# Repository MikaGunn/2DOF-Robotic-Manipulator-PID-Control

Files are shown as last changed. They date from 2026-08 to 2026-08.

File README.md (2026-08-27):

# 2-DOF Robotic Manipulator with PID Control

A complete mechatronics project covering the design, simulation, fabrication, electronics integration and closed loop control of a **2 degree of freedom (2-DOF) planar robotic manipulator**.

The system combines mechanical CAD design, 3D printed components, Arduino based motor control, encoder feedback, inverse kinematics and PID position control developed in MATLAB/Simulink.

<p align="center">
  2-DOF robotic manipulator
</p>

## Project Overview

The manipulator was developed as part of a university robotics and mechatronics project. Its two rotational joints allow the end effector to move within a 2D workspace. A belt and pulley transmission was used for the second link to improve stability and reduce the need to mount an additional motor directly on the moving arm.

The project includes:

- Mechanical concept development and CAD modelling
- Forward and inverse kinematics
- Denavit Hartenberg modelling
- 3D-printed custom components
- Arduino Mega 2560 control
- EMG30 DC motors with encoders
- L298N H-bridge motor driver
- Closed loop PID position control
- MATLAB/Simulink control system development
- Encoder feedback and PWM motor actuation
- Experimental PID tuning and response analysis

## System Architecture

The control system receives a desired end effector position and converts it into target joint angles using inverse kinematics. Each joint then uses encoder feedback and PID control to reduce the difference between the desired and measured angular position.

```text
Target End-Effector Position (x, y)
              |
              v
      Inverse Kinematics
              |
        theta1, theta2
          /       \
         v         v
     PID Joint 1  PID Joint 2
         |           |
         v           v
     Motor Driver  Motor Driver
         |           |
         v           v
      DC Motor 1   DC Motor 2
         ^           ^
         |           |
      Encoder 1    Encoder 2
         \___________/
          Feedback Loop
```

<p align="center">
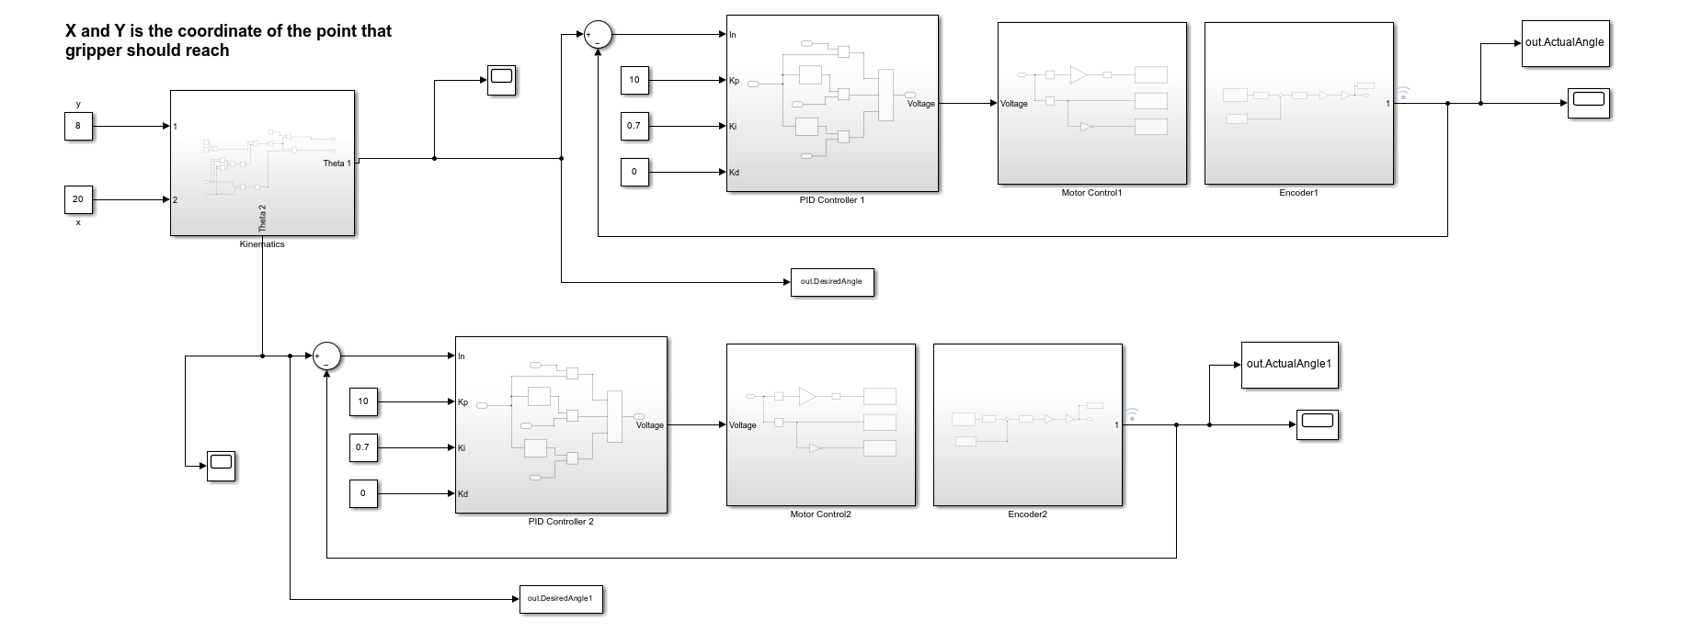
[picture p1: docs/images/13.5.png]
Simulink control architecture
  
</p>

## Mechanical Design

CAD modelling was carried out using **Onshape** and **SolidWorks**. The assembly includes two rotational joints, two links, a gripper, belt and pulley transmission, motors, bearings and custom printed interfaces.

Two custom parts designed for the system include:

- **Gripper** — includes inner gripping channels and a square mounting interface for the arm.
- **Motor joint** — designed to securely connect the EMG30 motor to the first arm and transfer rotational motion.

The complete CAD assembly is included as a STEP file in the `CAD/` directory.

<p align="center">
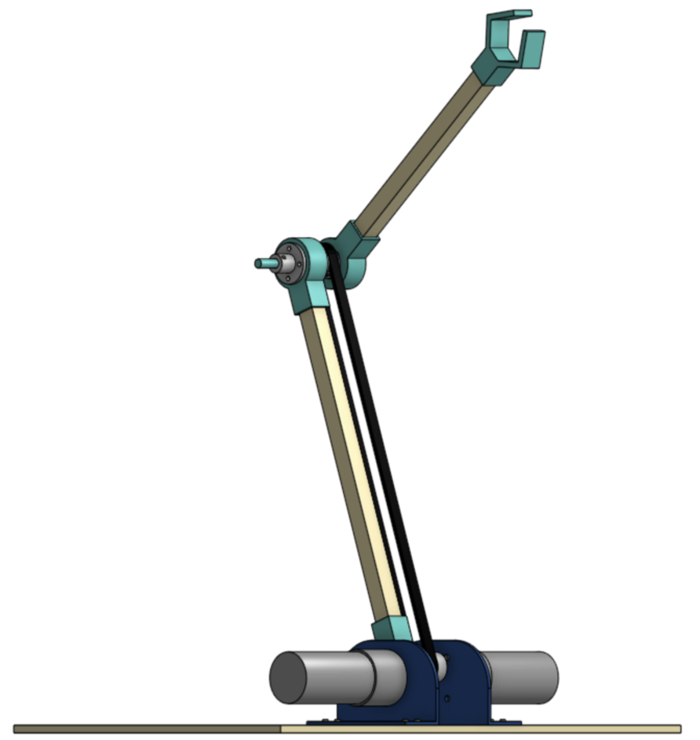
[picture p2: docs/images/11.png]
CAD assembly
  
</p>

## Electronics

### Main Components

| Component | Purpose |
|---|---|
| Arduino Mega 2560 | Main controller and encoder interface |
| 2 × EMG30 DC motors with encoders | Joint actuation and position feedback |
| L298N motor driver | Bidirectional motor control |
| 12 V external power supply | Motor power |
| GT2 belt and pulleys | Motion transmission to the second link |

The Arduino reads encoder signals, computes motor position error and drives the motors through PWM and direction signals.

## PID Control

Each joint uses a feedback PID controller. The control objective is to track the target joint position while reducing overshoot, rise time and steady state error.

The tuned controller values used in the project were:

| Gain | Value |
|---|---:|
| Kp | 1.0 |
| Ki | 0.7 |
| Kd | 0.0 |

The Arduino implementation updates the PID calculation every **50 ms**, includes encoder interrupt handling, output limiting and a minimum PWM compensation to overcome motor deadband/static friction.

<p align="center">
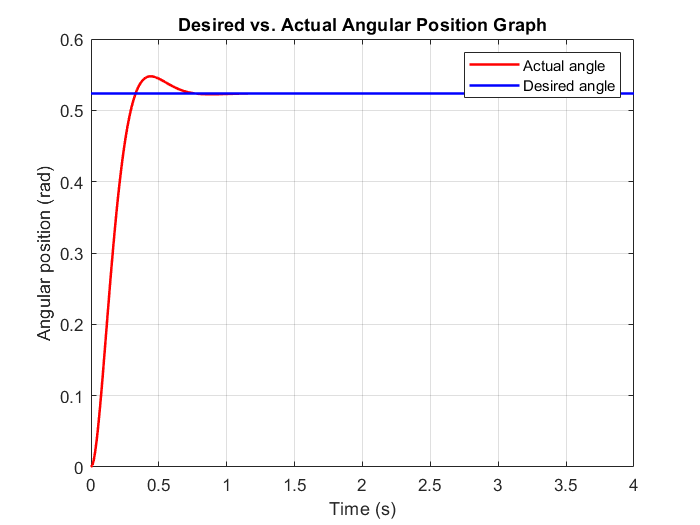
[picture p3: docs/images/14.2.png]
PID response result
  
</p>

## Kinematics

For a planar 2-link manipulator, the end effector coordinates are determined from the link lengths and joint angles.

Forward kinematics:

```text
x = L1 cos(theta1) + L2 cos(theta1 + theta2)
y = L1 sin(theta1) + L2 sin(theta1 + theta2)
```

Inverse kinematics is used to calculate the two required joint angles for a desired `(x, y)` end effector target.

## Repository Structure

```text
2DOF-Robotic-Manipulator-PID-Control/
├── CAD/
│   └── Robot_CAD.step
├── control/
│   ├── Arduino_PID_controller.ino
│   └── Simulink_PID_controller.slx
├── docs/
│   └── images
│   └── 2DOF Robotic Manipulator Report
├── .gitignore
└── README.md
```

## Files

### `CAD/Robot_CAD.step`
Full 3D CAD assembly of the robotic manipulator in STEP format.

### `control/Simulink_PID_controller.slx`
MATLAB/Simulink model containing the kinematics, PID, motor control and encoder feedback subsystems.

### `control/Arduino_PID_controller.ino`
Arduino implementation of the dual motor PID controller. It includes:

- Encoder interrupts
- Independent PID loops for both motors
- PWM motor output
- Direction control
- Error threshold handling
- Minimum PWM compensation
- Automatic target switching for repeated motion tests
- Serial monitoring of position and target values

## Hardware Used

- Arduino Mega 2560
- 2 × EMG30 DC motors with encoders
- L298N dual H-bridge motor driver
- GT2 belt and pulley system
- Bearings and shaft components
- 3D printed gripper and mechanical joints
- Wooden arm links and base
- 12 V motor power supply

## Software Used

- MATLAB
- Simulink
- Arduino IDE
- SolidWorks
- Onshape

## Key Engineering Challenges

The project highlighted several practical robotics challenges:

- Mechanical alignment influenced encoder accuracy.
- Belt tension affected vibration and motion quality.
- Gravity had a larger effect on the first joint because it supported the complete arm assembly.
- PID tuning required balancing response speed, overshoot and steady state error.
- Some Simulink to hardware compilation issues led to development of a standalone Arduino PID implementation as an alternative controller.

## Future Improvements

Possible extensions include:

- Dual sided axle support to improve rigidity
- Aluminium or carbon fibre links to reduce flex and vibration
- Servo actuated gripper
- Improved cable management
- Trajectory planning instead of point to point motion
- Automatic PID tuning
- Workspace and path visualisation
- ROS 2 integration
- Joint limit and safety protection

## Skills Demonstrated

`Robotics` · `Mechatronics` · `Control Systems` · `PID Control` · `Arduino` · `MATLAB` · `Simulink` · `CAD` · `SolidWorks` · `Onshape` · `3D Printing` · `Forward Kinematics` · `Inverse Kinematics` · `Encoder Feedback` · `PWM Motor Control`

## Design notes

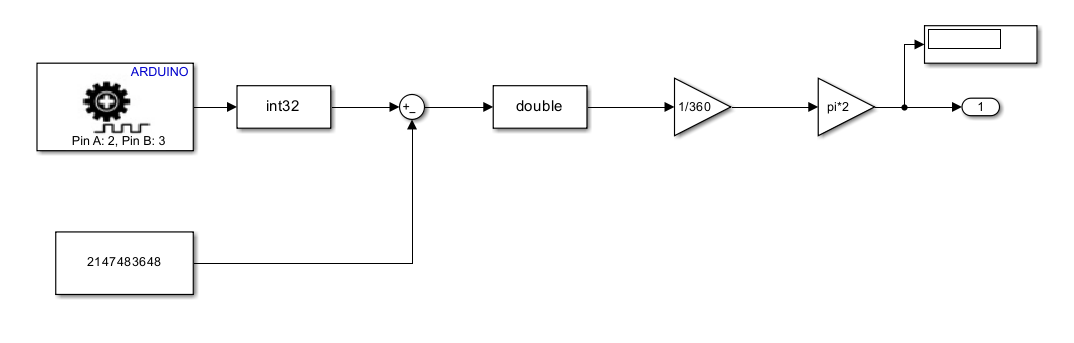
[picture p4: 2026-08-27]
docs/images/13.1.png

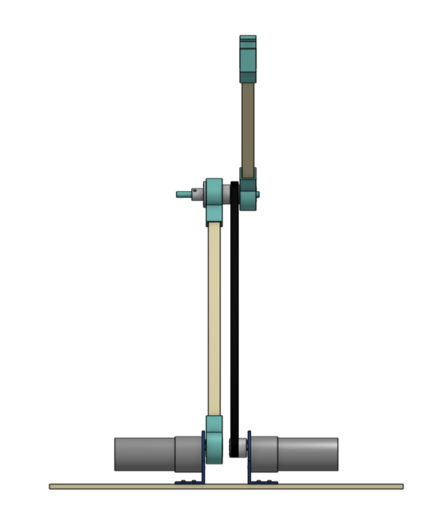
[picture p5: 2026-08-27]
docs/images/9.0.png

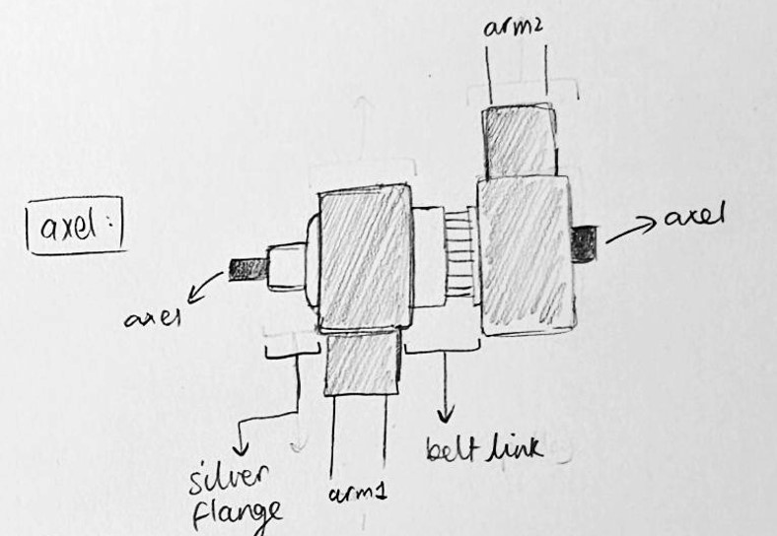
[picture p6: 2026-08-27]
docs/images/8.1.jpg

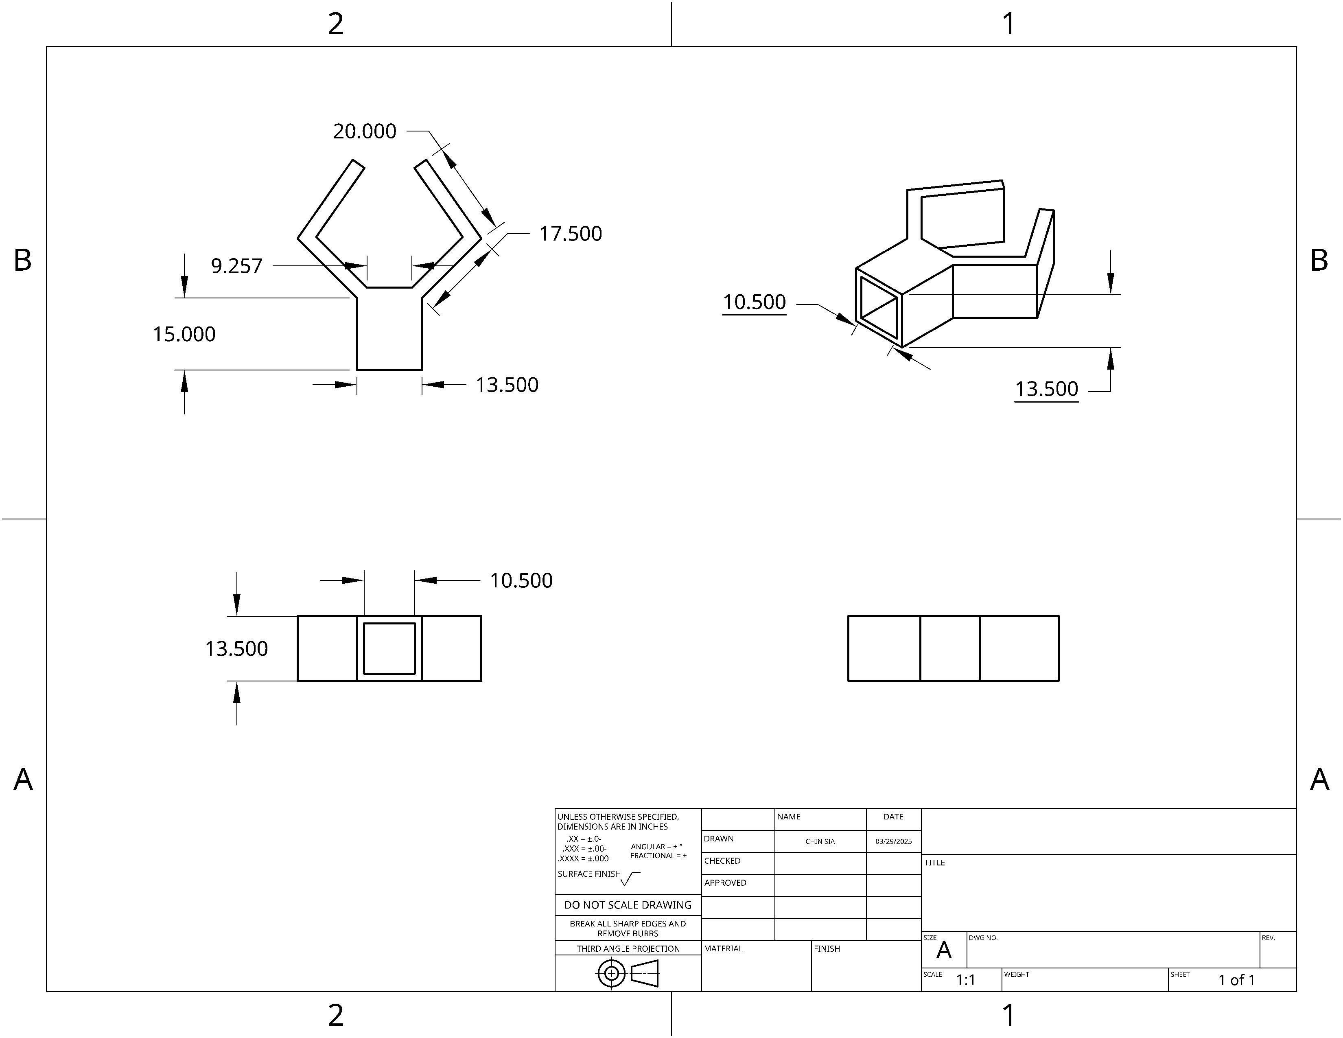
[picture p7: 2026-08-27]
docs/images/7.1.jpeg

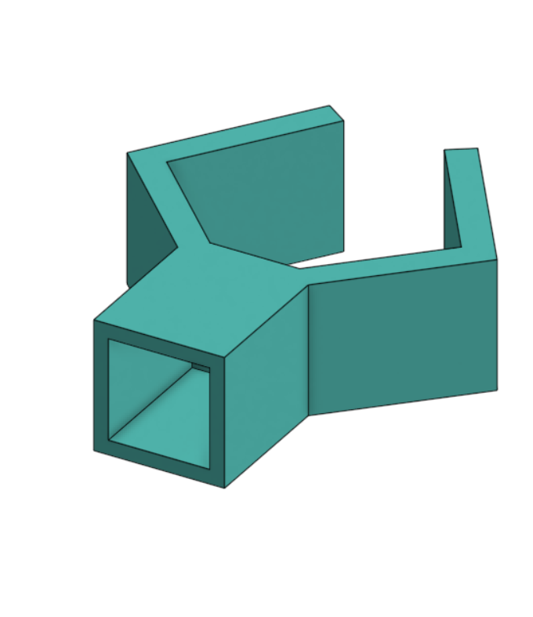
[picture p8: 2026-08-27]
docs/images/7.0.png

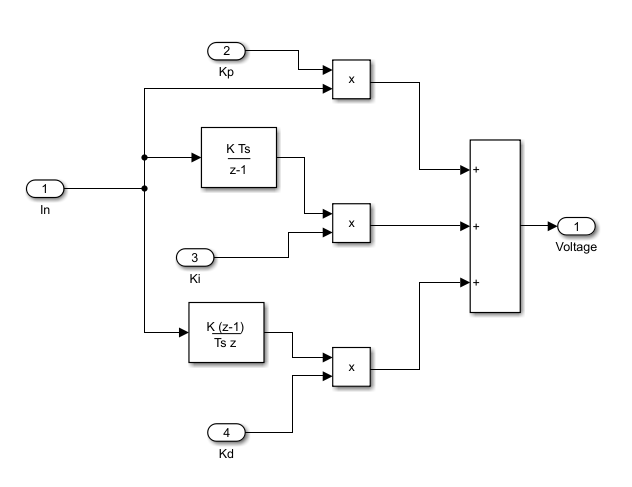
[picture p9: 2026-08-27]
docs/images/13.0.png

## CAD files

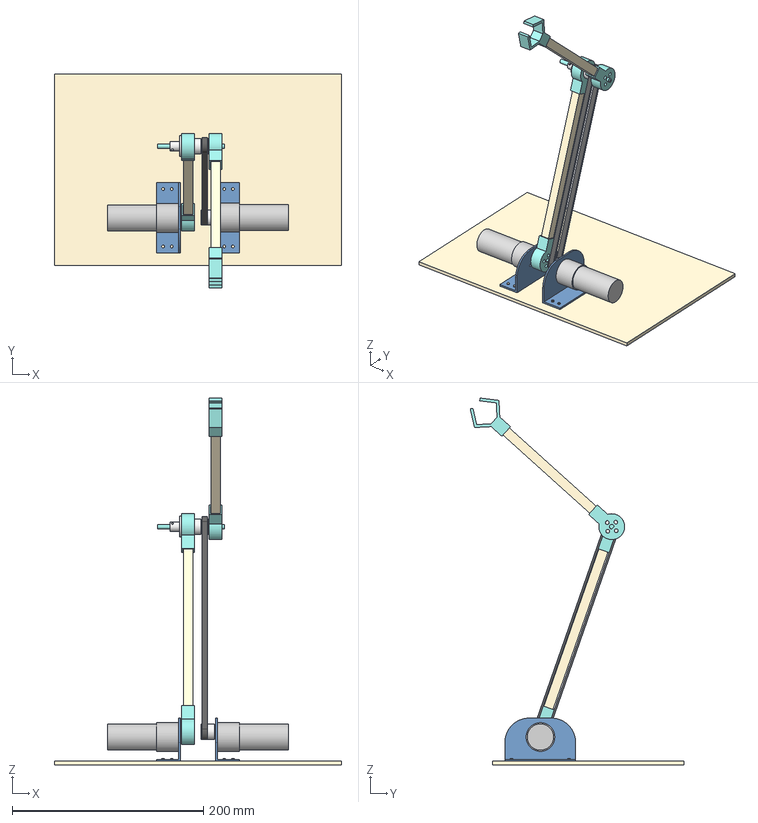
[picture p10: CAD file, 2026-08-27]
CAD/Robot_CAD.step
300.0 x 223.2 x 383.4 mm
Spur gear (20 teeth) x 2

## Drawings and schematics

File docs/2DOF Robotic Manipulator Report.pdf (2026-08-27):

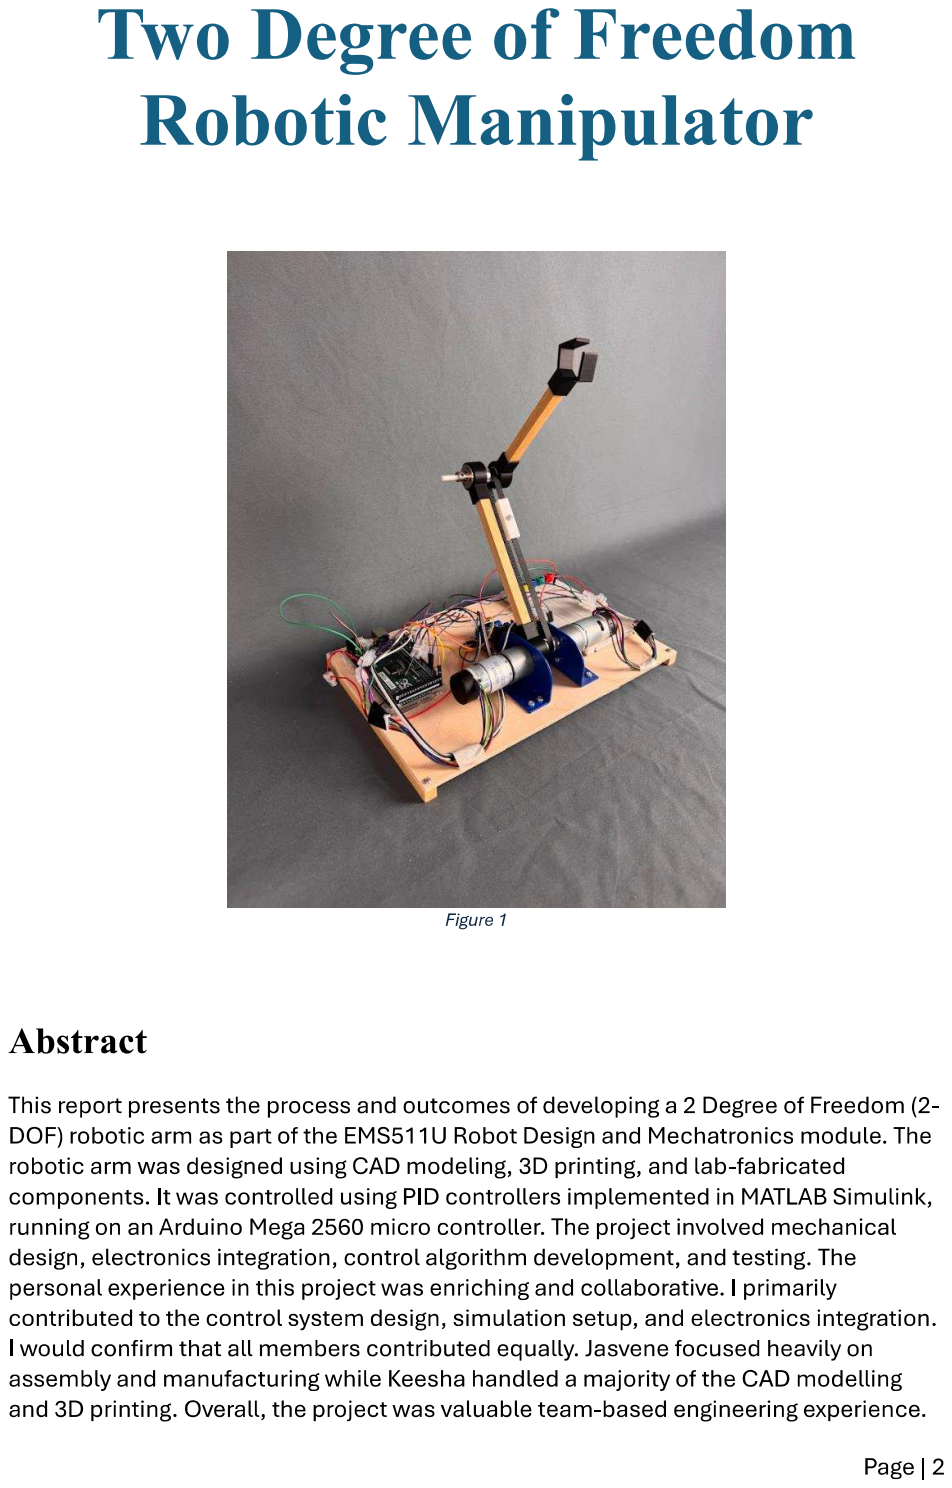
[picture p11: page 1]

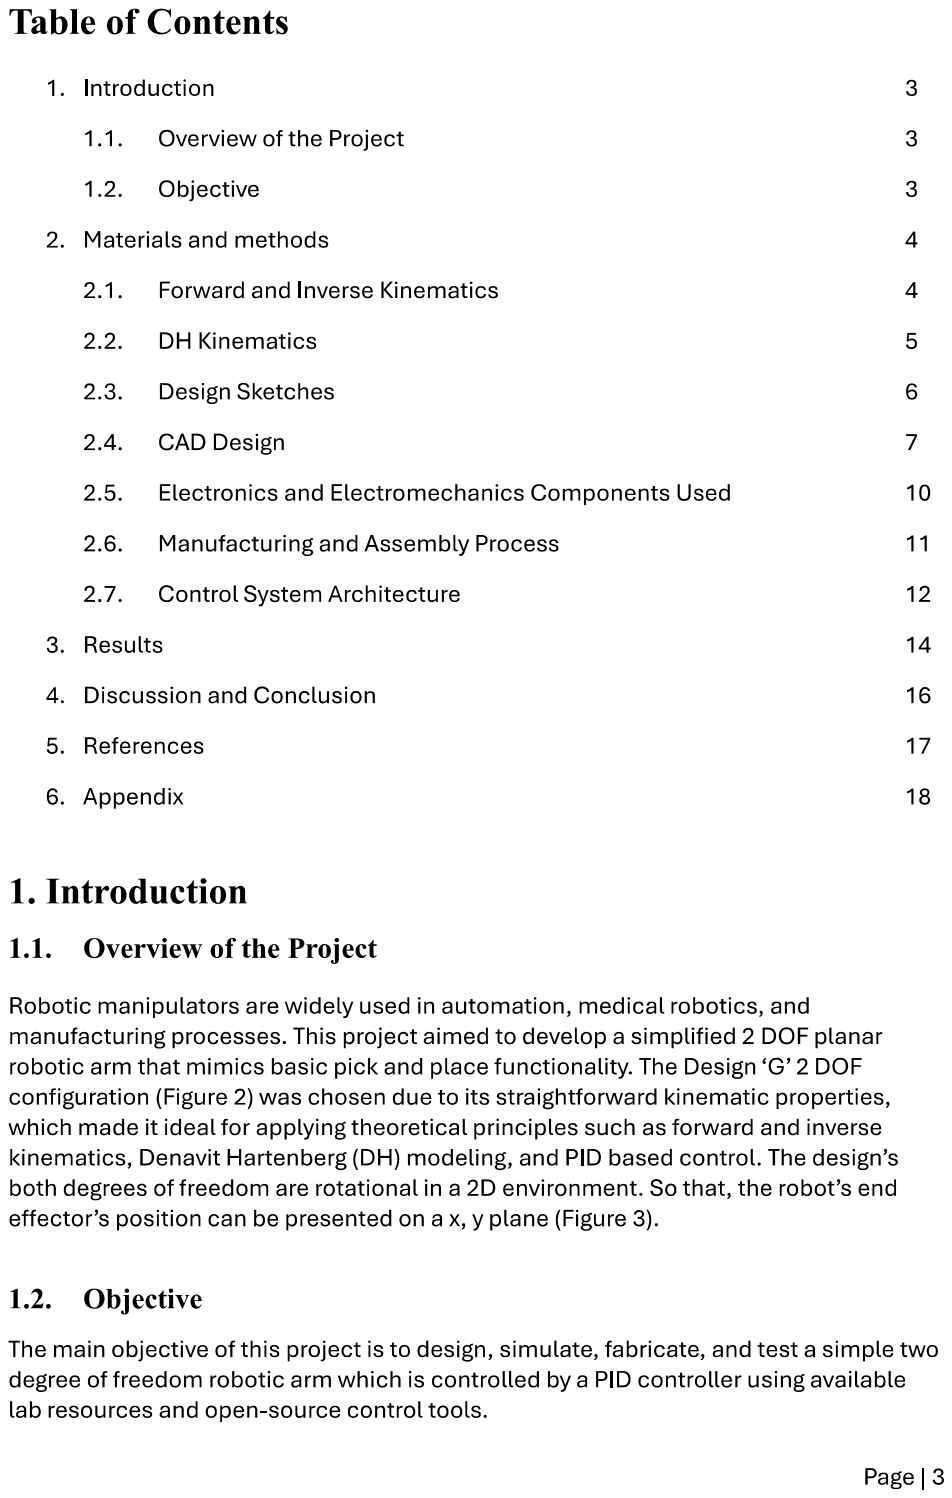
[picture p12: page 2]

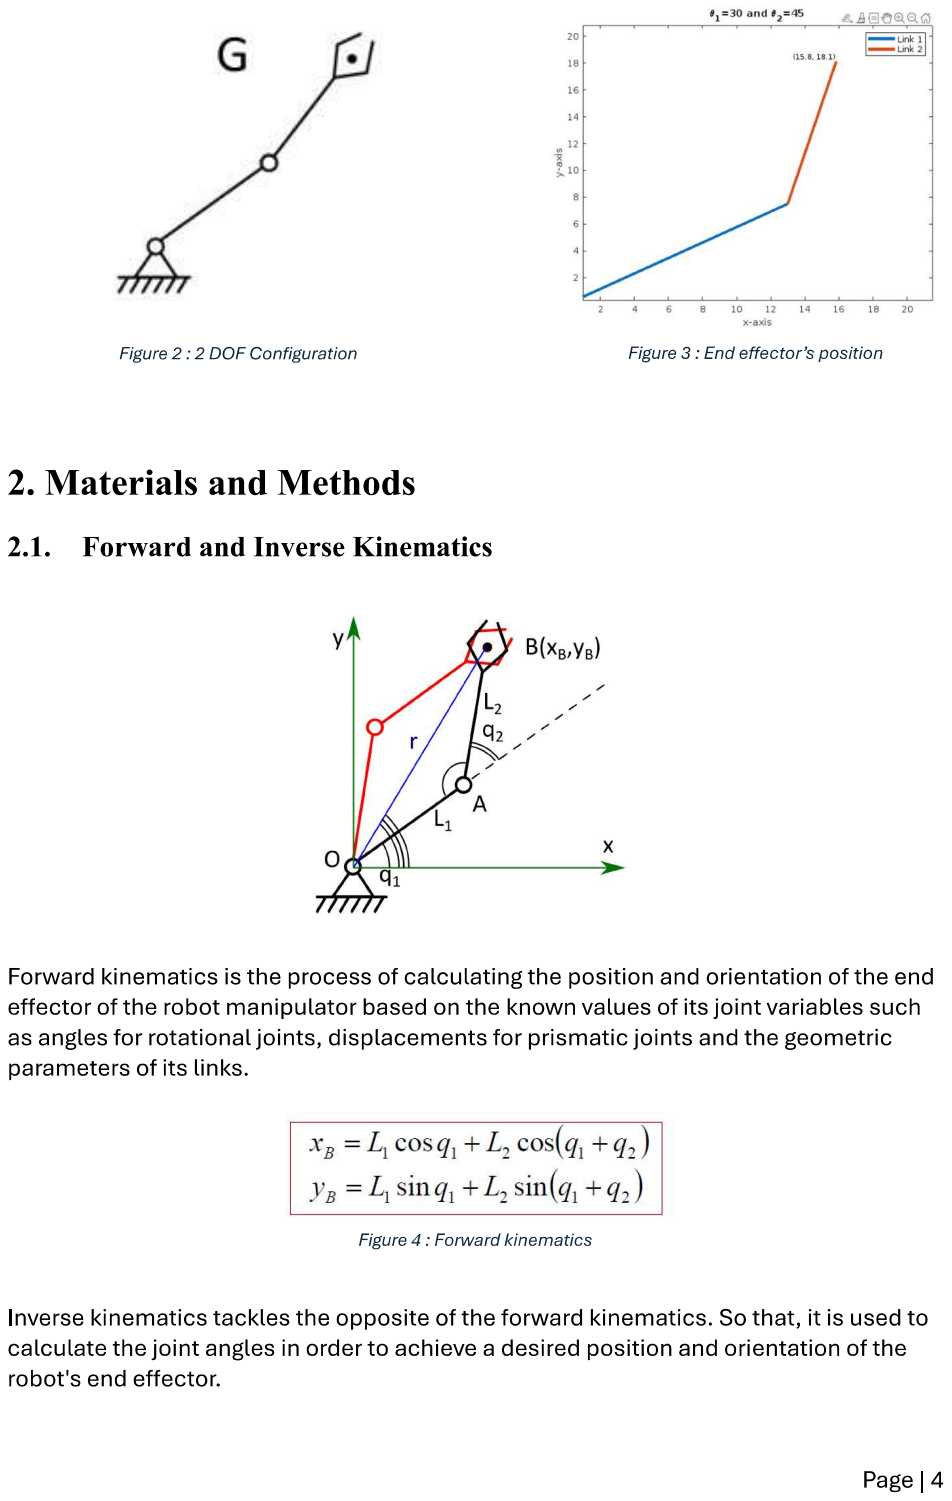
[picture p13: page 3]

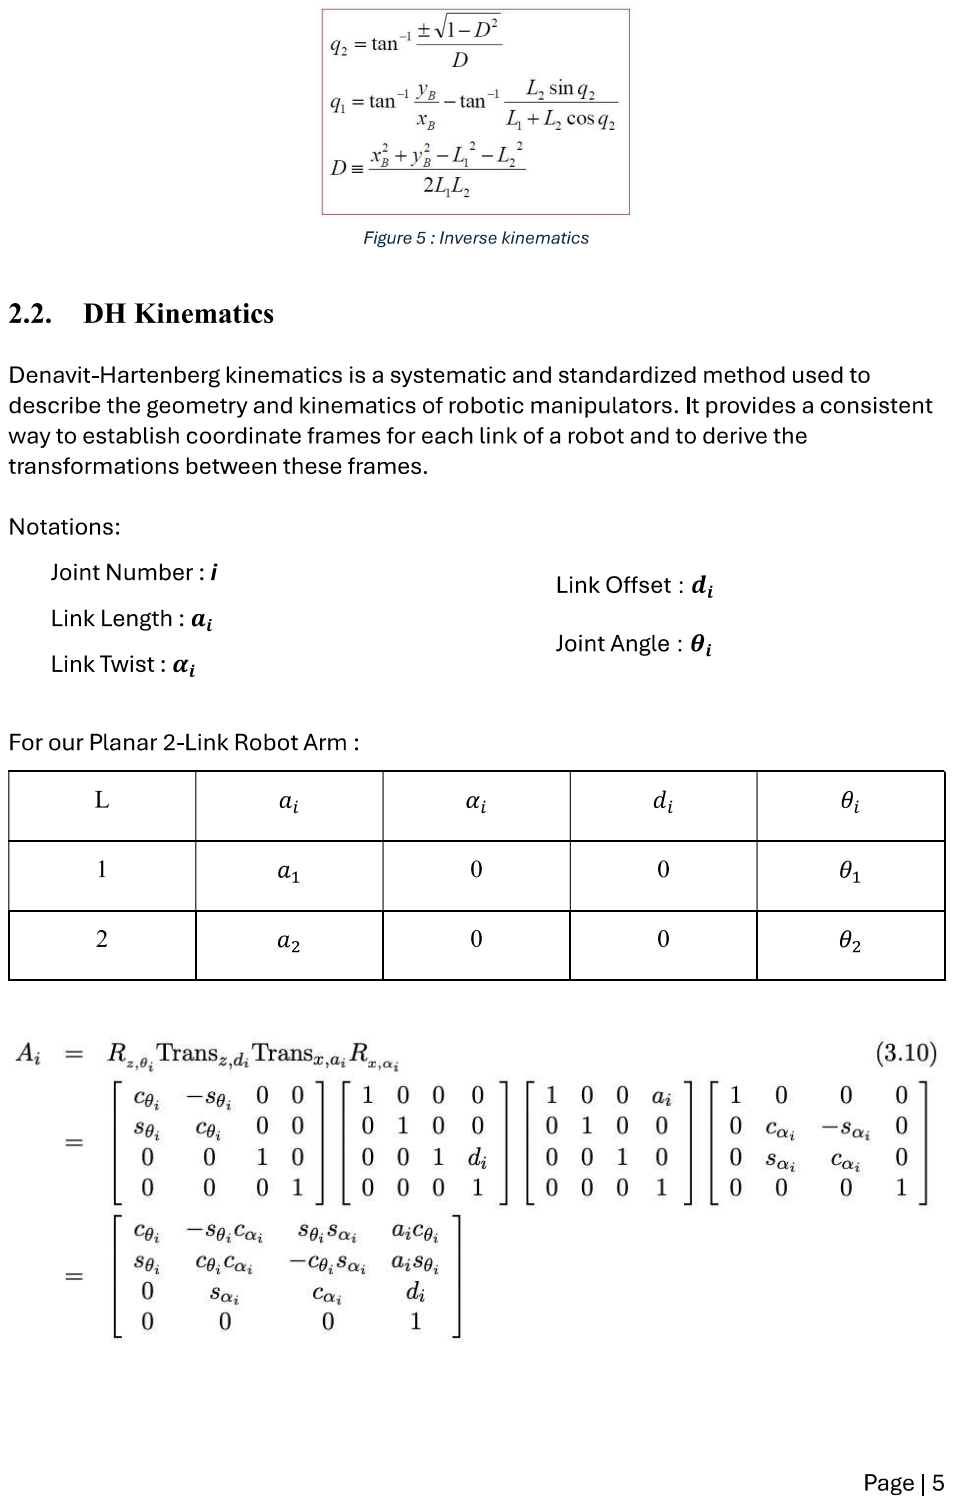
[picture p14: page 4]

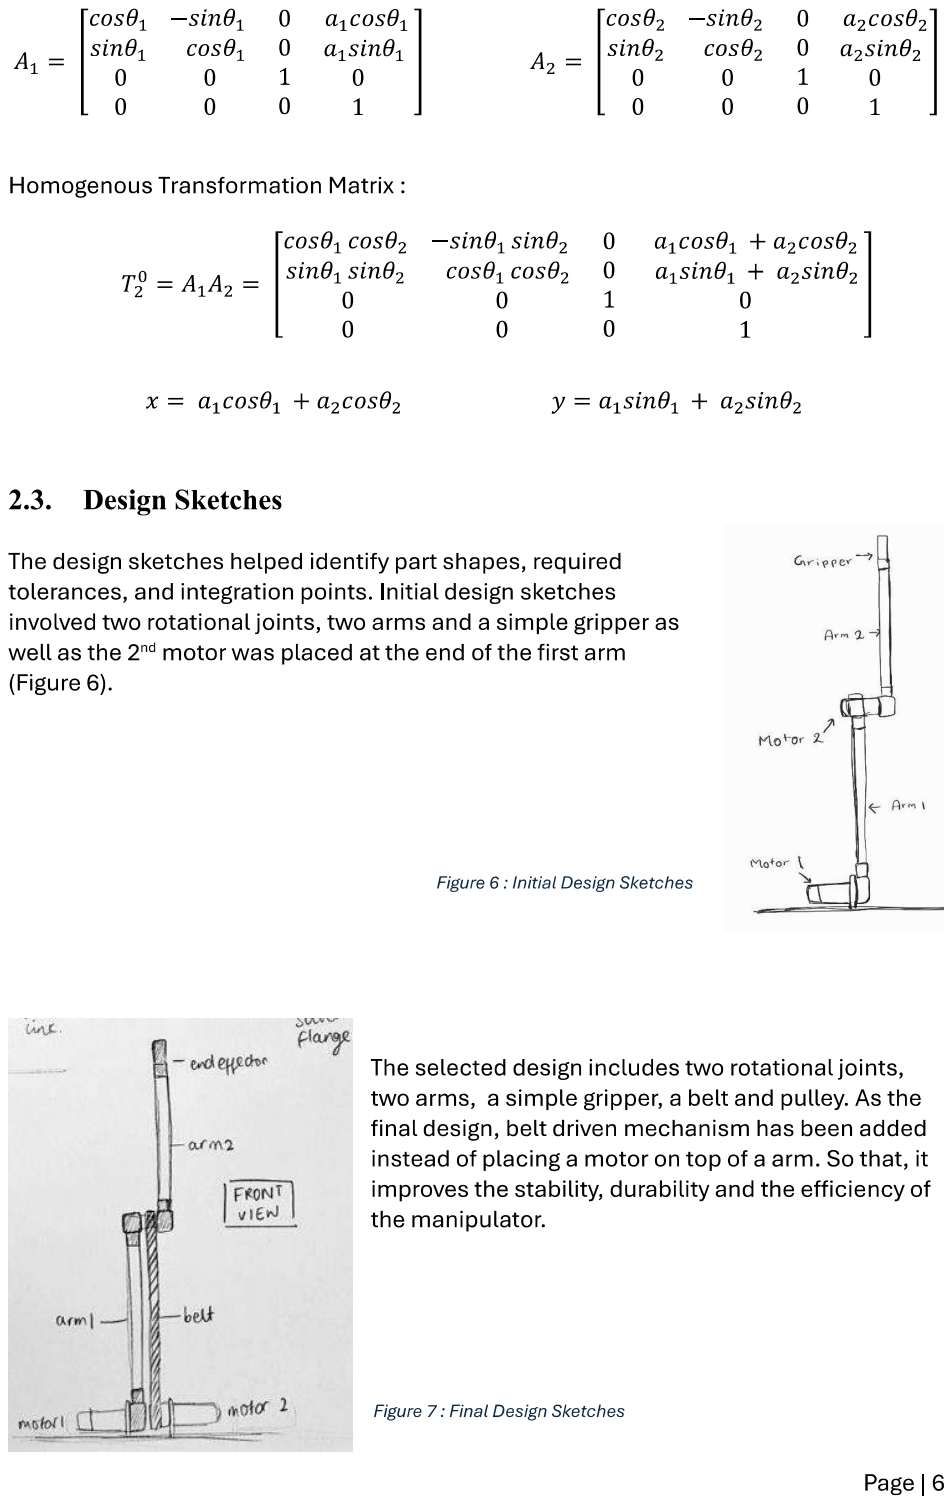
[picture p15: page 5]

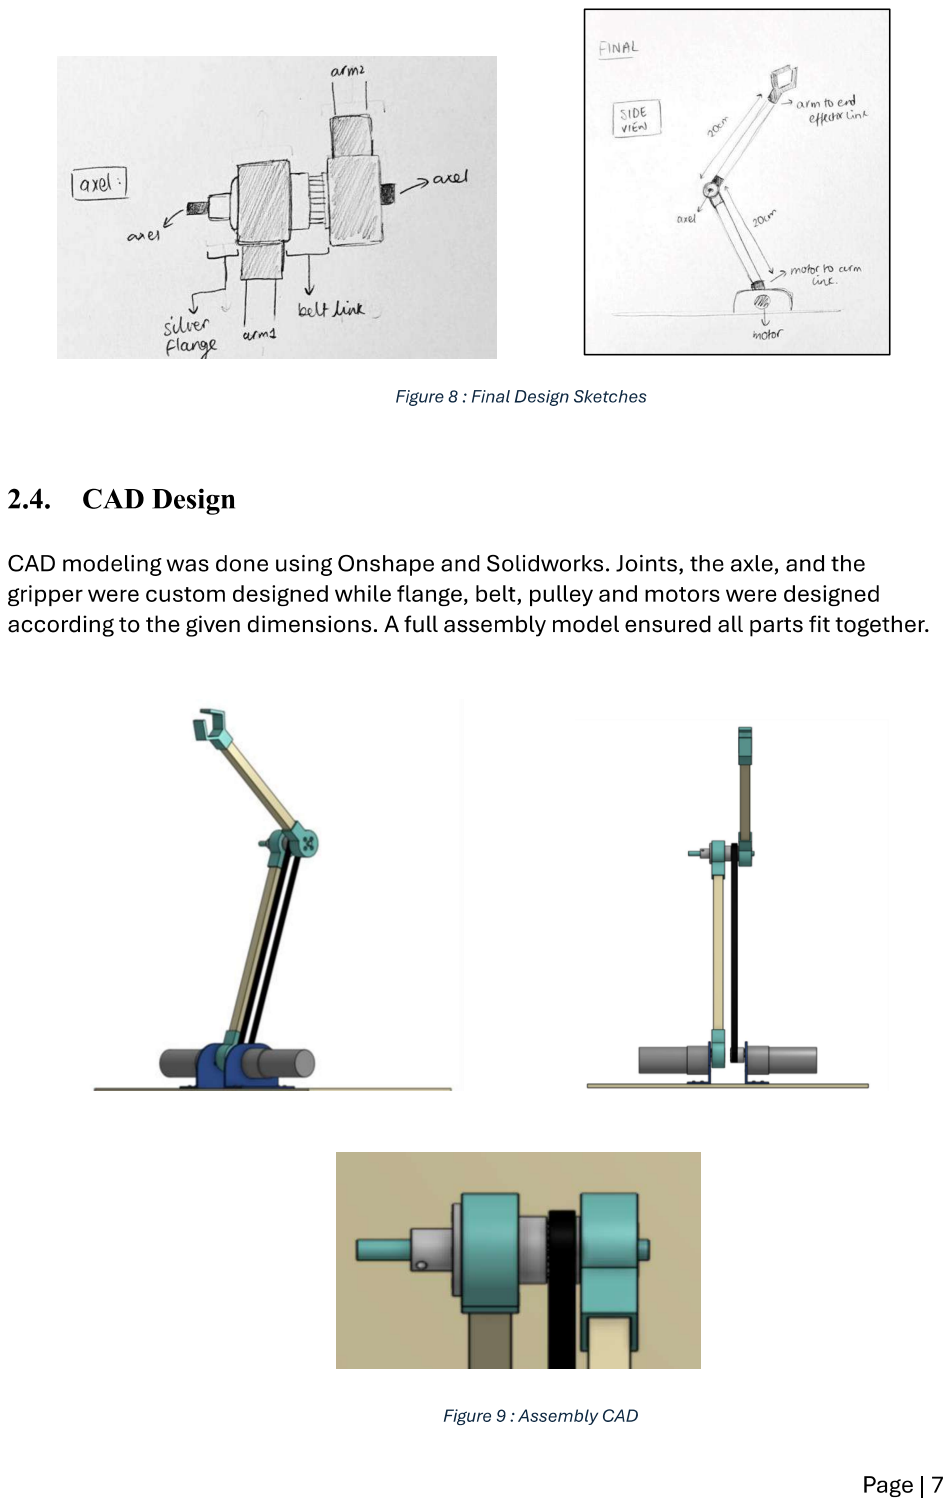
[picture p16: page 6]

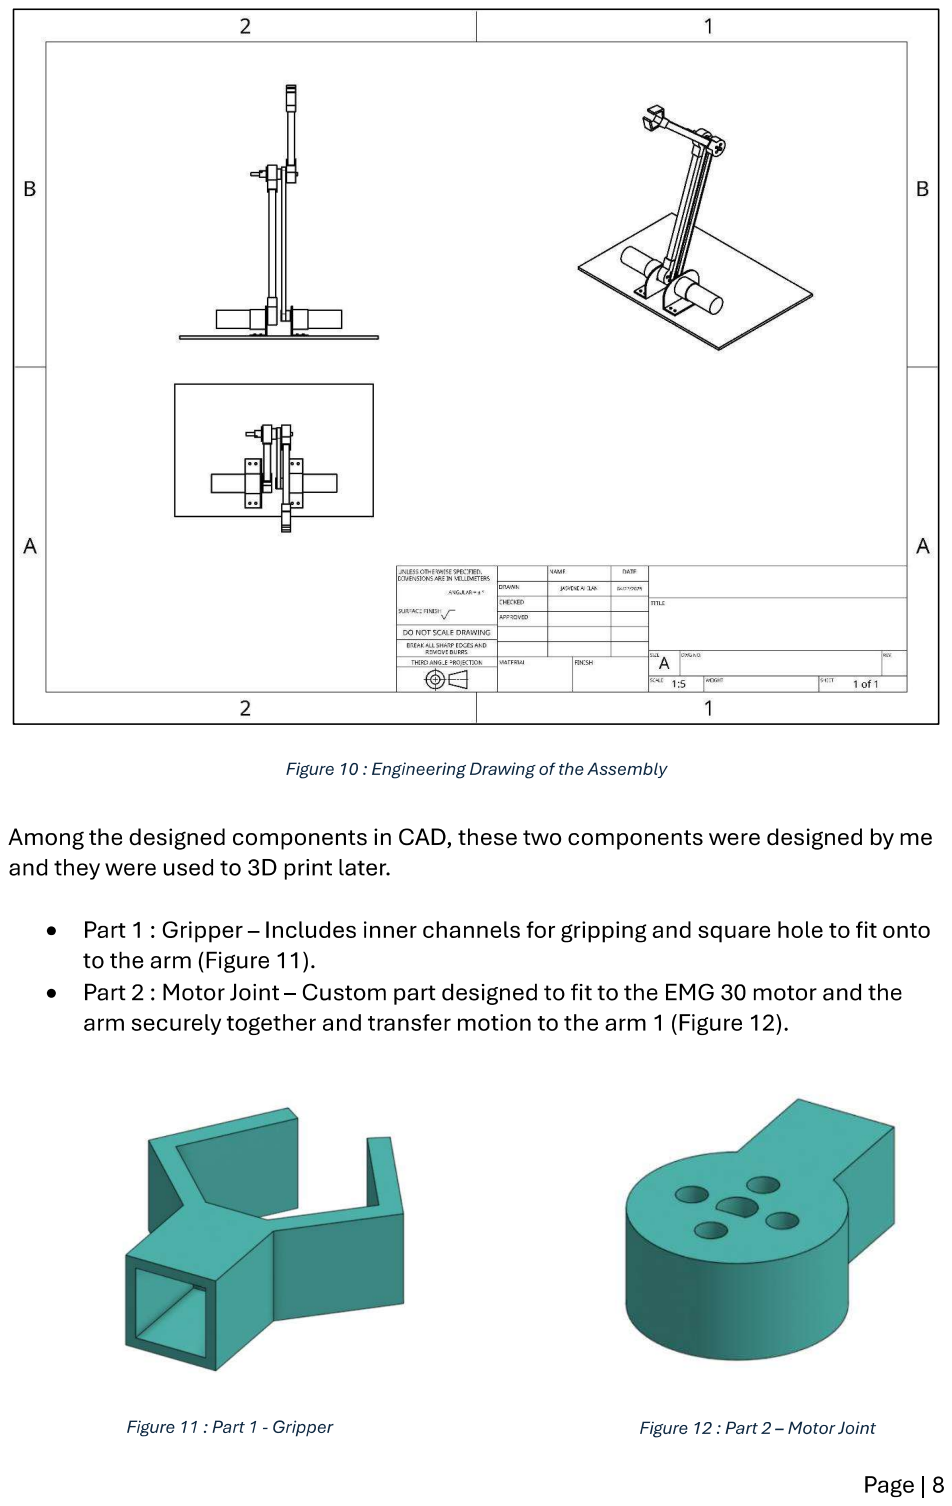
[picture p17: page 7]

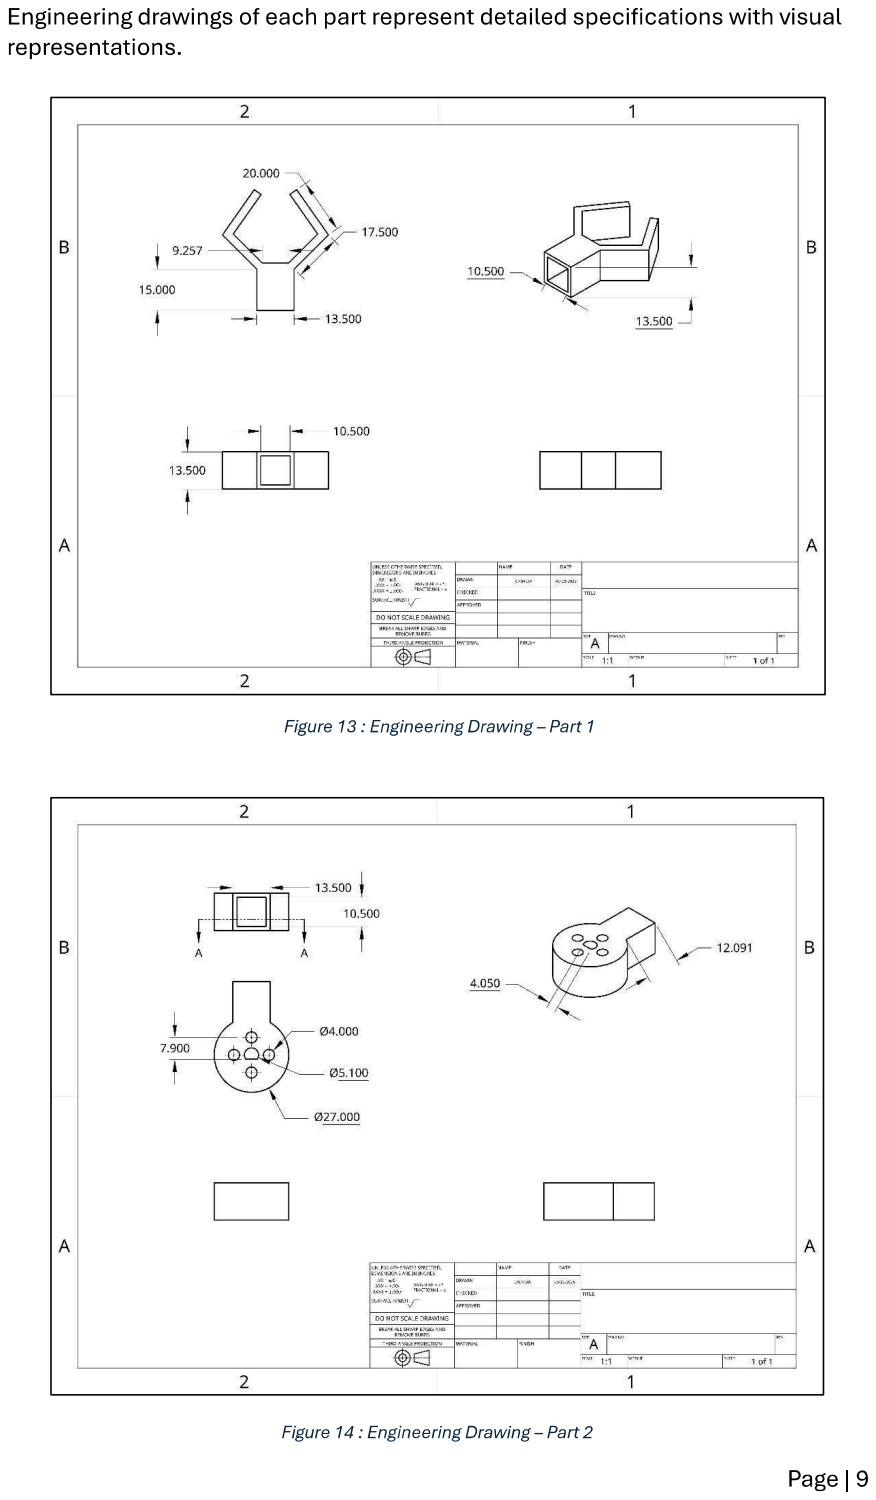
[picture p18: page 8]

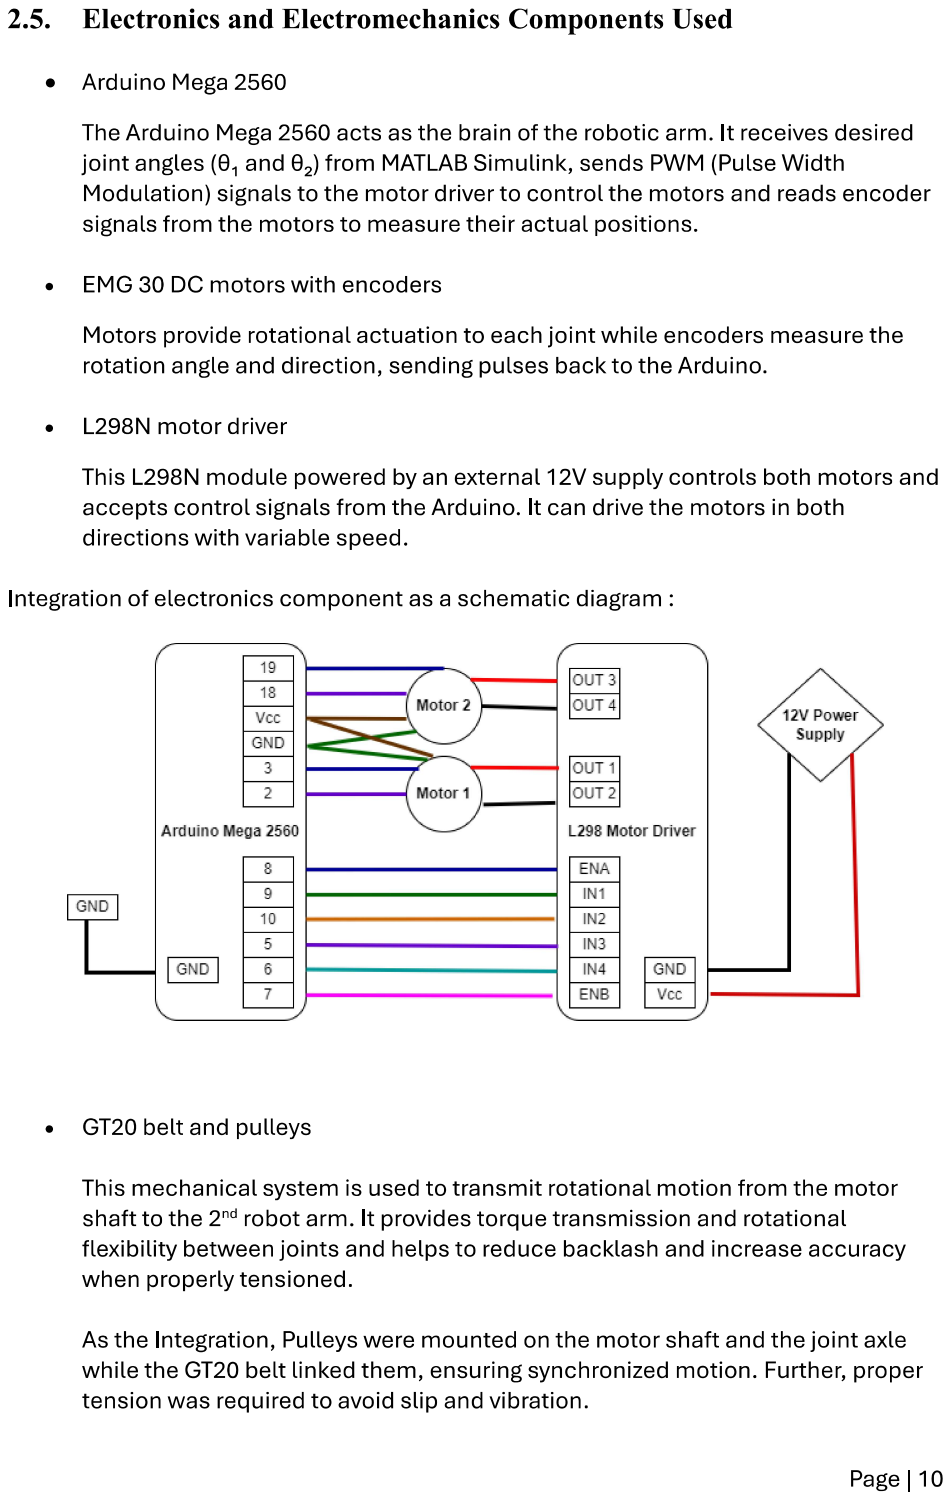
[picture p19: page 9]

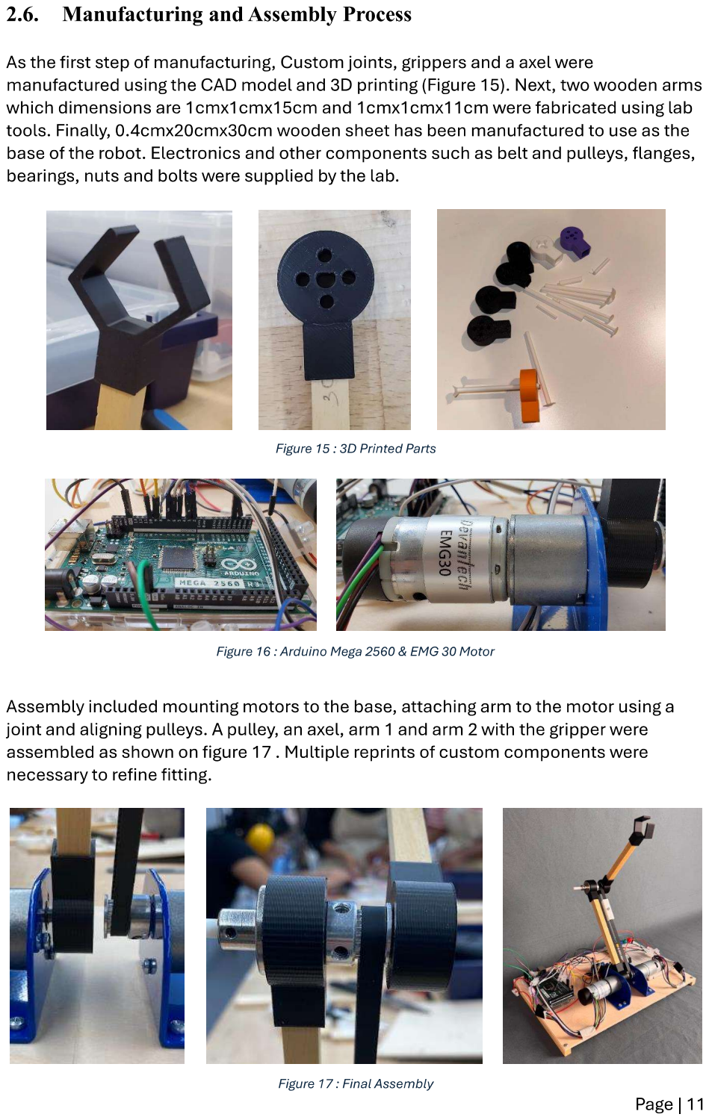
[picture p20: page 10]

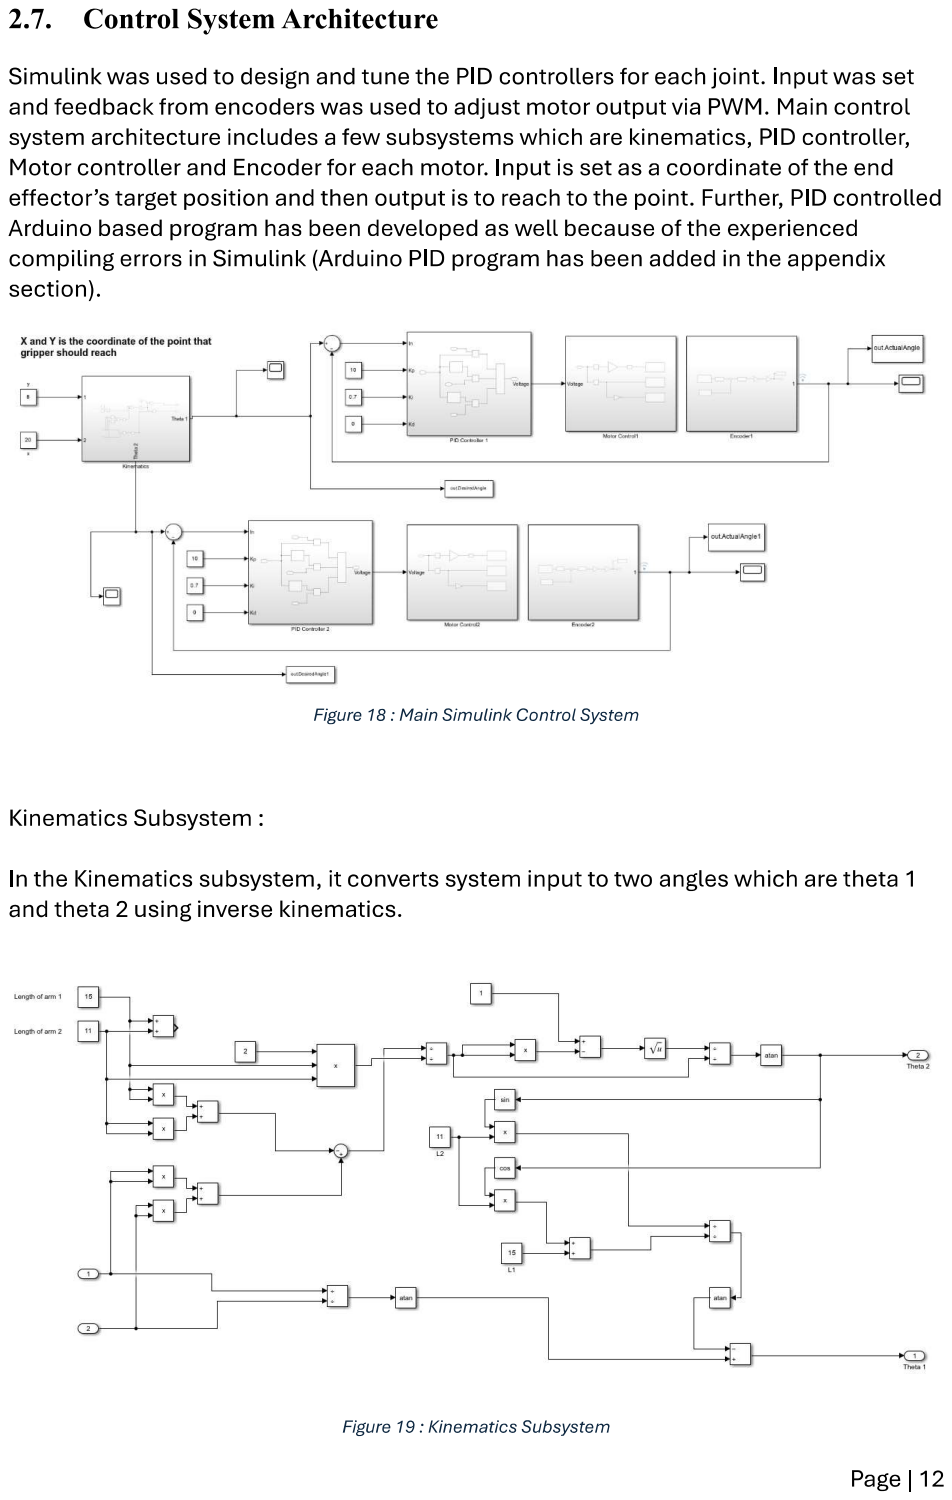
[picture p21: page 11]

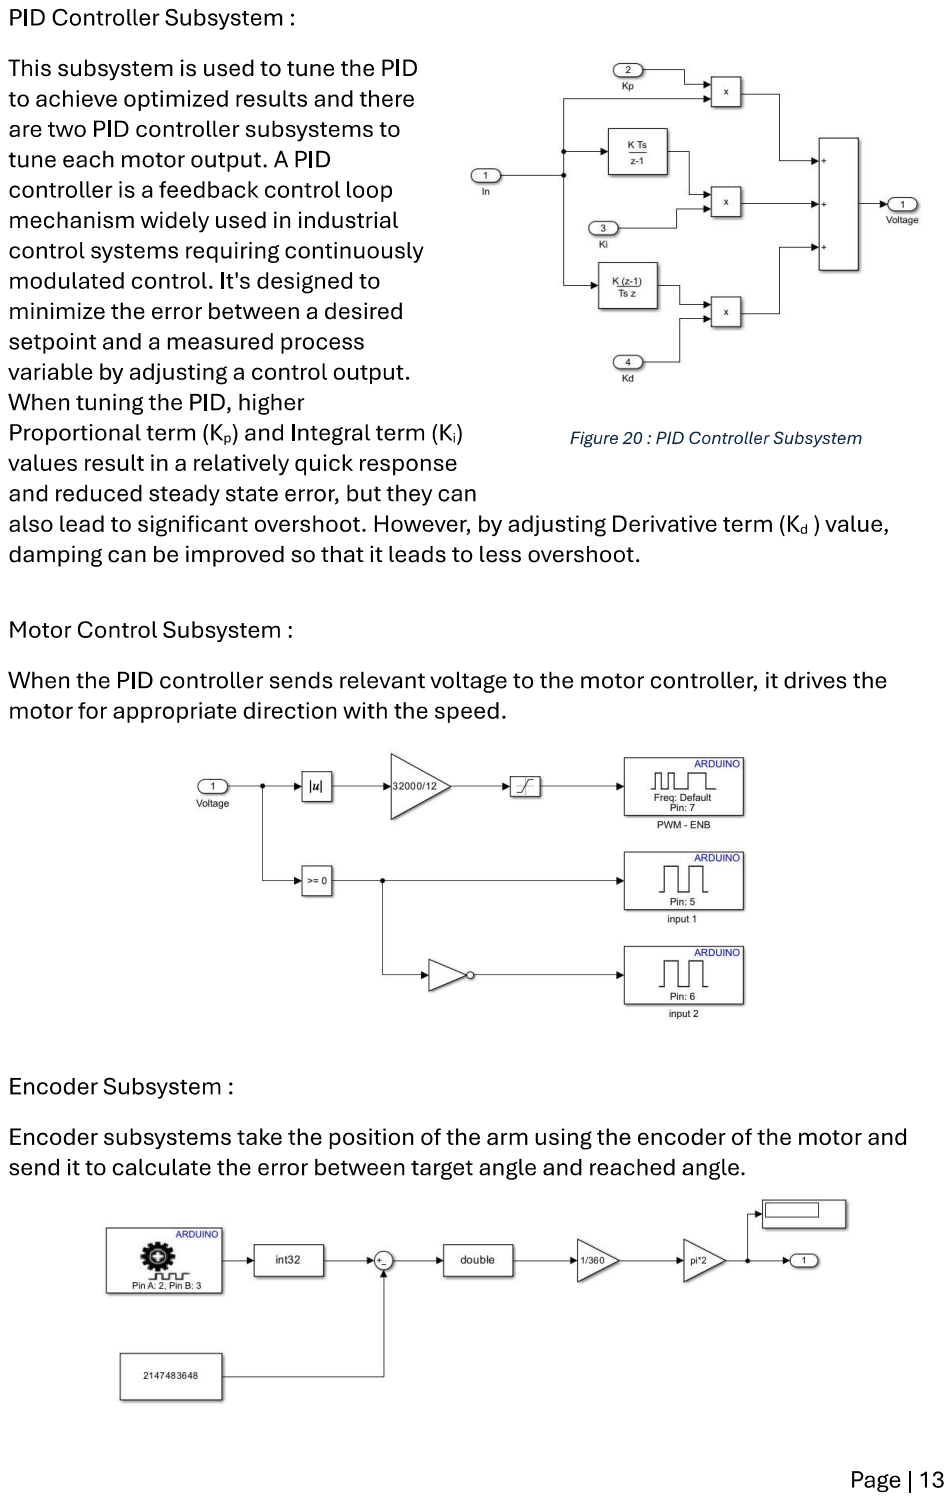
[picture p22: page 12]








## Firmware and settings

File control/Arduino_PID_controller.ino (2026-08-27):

// These volatile variables keep track of encoder pulses for each motor.
// The "volatile" keyword ensures the compiler doesn't optimize these variables away,
// as they are updated in interrupt service routines (ISRs).
volatile long encoder1Count = 0;
volatile long encoder2Count = 0;

// Define motor control pins for Motor 1 and Motor 2.
// ENA PWM-ENAbled pins for speed control.
// IN's control motor direction.

// Motor 1
#define ENA 8 // YELLOW
#define IN1 9 // BLUE
#define IN2 10 // WHITE

// Motor 2
#define ENB 7 // YELLOW
#define IN3 5 // BLUE
#define IN4 6 // WHITE

// Define the pins connected to the hall sensor outputs (encoders).
// Pins 2 and 3 are interrupt-capable on the Arduino Mega.

#define ENCA1 2  // (Blue) Hall Sensor Encoder A for motor 1
#define ENCB1 3  // (Purple) Hall Sensor Encoder B for motor 1

#define ENCA2 18  // (Blue) Hall Sensor Encoder A for motor 2
#define ENCB2 19  // (Purple) Hall Sensor Encoder B for motor 2


// Define the PID controller gains for each motor:
// Kp = Proportional gain, Ki = Integral gain, Kd = Derivative gain.
float Kp1 = 1, Ki1 = 0.7, Kd1 = 0;
float Kp2 = 1, Ki2 = 0.7, Kd2 = 0;

// Variables for PID control for Motor 1 and Motor 2.
float error1 = 0, lastError1 = 0, integral1 = 0;
float error2 = 0, lastError2 = 0, integral2 = 0;


// Define starting and target positions (in encoder counts) for relative movements.
// posA1/posA2 are the starting positions
// posB1/posB2 define how far to move
long posA1 = 0;           
long posB1 = 10;         

long posA2 = 0;
long posB2 = -20;

// Set the initial target positions to move from 0 to 100 counts.
long target1 = posB1;     
long target2 = posB2;

// Motion state indicates the current direction: 0 = moving forward (to B), 1 = returning (to A).
int motionState = 0;      

// Variables to track timing for PID updates and serial status prints.
unsigned long lastPIDTime = 0;
unsigned long lastPrintTime = 0;

// Acceptable error threshold for reaching the target (in encoder counts).
// The condition to detect when the target is reached now uses a threshold constant
// so that minor overshoots won’t prevent the motion state from switching.

const int ERROR_THRESHOLD = 5;

// Minimum PWM value to overcome static friction or deadband issues in the motor driver.
// In each PID update, if the computed output is nonzero but falls below a minimum value 
// (here defined as 30), the output is bumped up to that minimum. This should overcome 
// the motor’s static friction for small rotations
const int MIN_PWM = 30; 

void setup() {
  // Initialize serial communication at 9600 baud for debugging.
  Serial.begin(9600);

  // Configure motor control pins as outputs.
  pinMode(ENA, OUTPUT); pinMode(IN1, OUTPUT); pinMode(IN2, OUTPUT);
  pinMode(ENB, OUTPUT); pinMode(IN3, OUTPUT); pinMode(IN4, OUTPUT);

  // Configure encoder pins as inputs with internal pull-up resistors enabled.
  // This is useful for the open-collector outputs of hall sensors.
  pinMode(ENCA1, INPUT_PULLUP);
  pinMode(ENCB1, INPUT_PULLUP);
  pinMode(ENCA2, INPUT_PULLUP);
  pinMode(ENCB2, INPUT_PULLUP);

  // Attach interrupt service routines (ISRs) to the encoder channel A pins.
  // These interrupts trigger on a rising edge, ensuring accurate count updates.
  attachInterrupt(digitalPinToInterrupt(ENCA1), encoder1ISR, RISING);
  attachInterrupt(digitalPinToInterrupt(ENCA2), encoder2ISR, RISING);

  // Initialize encoder counts to zero.
  encoder1Count = 0;
  encoder2Count = 0;
}

void loop() {
  // Capture the current time in milliseconds.
  unsigned long now = millis();

  // Run the PID control loops every 50ms.
  if (now - lastPIDTime >= 50) {
    updateMotor1PID();
    updateMotor2PID();
    lastPIDTime = now;
  }

  // Print status (encoder counts, target positions, and motion state) every 500ms.
  if (now - lastPrintTime >= 500) {
    printStatus();
    lastPrintTime = now;
  }

  // Check if both motors have reached their target positions within the ERROR_THRESHOLD.
  if (abs(encoder1Count - target1) < ERROR_THRESHOLD && abs(encoder2Count - target2) < ERROR_THRESHOLD) {
    // Stop both motors.
    setMotor(ENA, IN1, IN2, 0);
    setMotor(ENB, IN3, IN4, 0);
    delay(500);  // Brief delay to ensure motors have fully stopped.

    // Reverse the direction of movement:
    // If the current motion state is 0 (moving forward), set target to return to start.
    // If the state is 1 (returning), set target to move forward.
    if (motionState == 0) {
      target1 = posA1;  // Return to starting position (0)
      target2 = posA2;
      motionState = 1;
    } else {
      target1 = posB1;  // Move forward by the defined count (e.g., 100)
      target2 = posB2;
      motionState = 0;
    }

    // Reset encoder counts to zero to use relative movement for the next cycle.
    encoder1Count = 0;
    encoder2Count = 0;

    // Reset PID integrals and previous errors to prevent windup.
    integral1 = 0;
    integral2 = 0;
    lastError1 = 0;
    lastError2 = 0;
  }
}


// Update PID control for Motor 1.
void updateMotor1PID() {
  // Read the current encoder count.
  long currentPos = encoder1Count;
  // Calculate the error between the target and current position.
  error1 = target1 - currentPos;
  // Integrate the error over time (assuming a 50ms loop, i.e., 0.05 seconds).
  integral1 += error1 * 0.05;
  // Calculate the derivative (rate of change) of the error.
  float derivative = (error1 - lastError1) / 0.05;

  // Compute the PID output using the proportional, integral, and derivative terms.
  float output = Kp1 * error1 + Ki1 * integral1 + Kd1 * derivative;
  // Constrain the output to the valid PWM range (-255 to 255).
  output = constrain(output, -255, 255);

  // Enforce a minimum PWM to overcome static friction (deadband compensation).
  if (abs(output) > 0 && abs(output) < MIN_PWM) {
    output = (output > 0) ? MIN_PWM : -MIN_PWM;
  }

  // Send the computed PWM and direction to the motor.
  setMotor(ENA, IN1, IN2, output);

  // Update last error for the next PID cycle.
  lastError1 = error1;
}

// Update PID control for Motor 2.
void updateMotor2PID() {
  // Read the current encoder count.
  long currentPos = encoder2Count;
  // Calculate the error.
  error2 = target2 - currentPos;
  // Integrate the error over time.
  integral2 += error2 * 0.05;
  // Calculate the derivative of the error.
  float derivative = (error2 - lastError2) / 0.05;

  // Compute the PID output.
  float output = Kp2 * error2 + Ki2 * integral2 + Kd2 * derivative;
  // Constrain the output to the PWM limits.
  output = constrain(output, -255, 255);

  // Enforce a minimum PWM if needed.
  if (abs(output) > 0 && abs(output) < MIN_PWM) {
    output = (output > 0) ? MIN_PWM : -MIN_PWM;
  }

  // Update the motor with the computed value.
  setMotor(ENB, IN3, IN4, output);

  // Update last error for Motor 2.
  lastError2 = error2;
}


// This helper function sets the motor speed and direction based on the given "speed" value.
void setMotor(int en, int in1, int in2, float speed) {
  // Use analogWrite to output PWM based on the absolute value of speed.
  analogWrite(en, abs(speed));

  // Set the motor direction:
  // Positive speed => one direction; negative speed => reverse.
  if (speed > 0) {
    digitalWrite(in1, HIGH);
    digitalWrite(in2, LOW);
  } else if (speed < 0) {
    digitalWrite(in1, LOW);
    digitalWrite(in2, HIGH);
  } else { // If speed is 0, stop the motor by setting both direction pins LOW.
    digitalWrite(in1, LOW);
    digitalWrite(in2, LOW);
  }
}


// Interrupt Service Routine (ISR) for Motor 1's encoder.
void encoder1ISR() {
  // Read both encoder channels.
  bool a = digitalRead(ENCA1);
  bool b = digitalRead(ENCB1);
  // Determine direction: if both signals are equal, decrement the count; otherwise, increment.
  encoder1Count += (a == b) ? -1 : 1;
}

// ISR for Motor 2's encoder.
void encoder2ISR() {
  bool a = digitalRead(ENCA2);
  bool b = digitalRead(ENCB2);
  encoder2Count += (a == b) ? -1 : 1;
}


// This function prints motor positions, target positions, and motion state to the serial monitor.
void printStatus() {
  Serial.print("M1 Pos: "); Serial.print(encoder1Count);
  Serial.print(" / Target: "); Serial.print(target1);
  Serial.print(" | M2 Pos: "); Serial.print(encoder2Count);
  Serial.print(" / Target: "); Serial.print(target2);
  Serial.print(" | State: "); Serial.println(motionState);
}
